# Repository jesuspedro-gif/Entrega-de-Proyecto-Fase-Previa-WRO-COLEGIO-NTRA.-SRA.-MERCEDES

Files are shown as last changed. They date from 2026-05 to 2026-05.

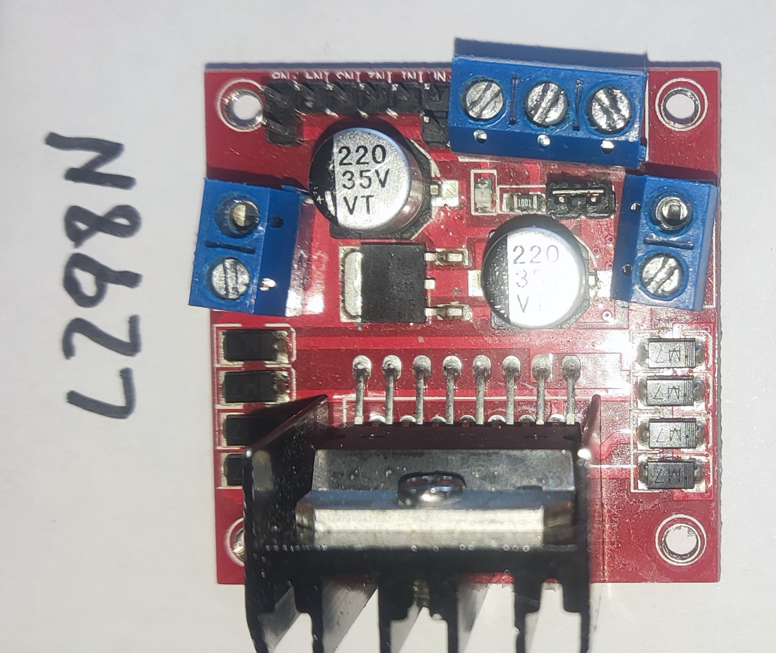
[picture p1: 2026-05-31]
images/L298N .jpeg

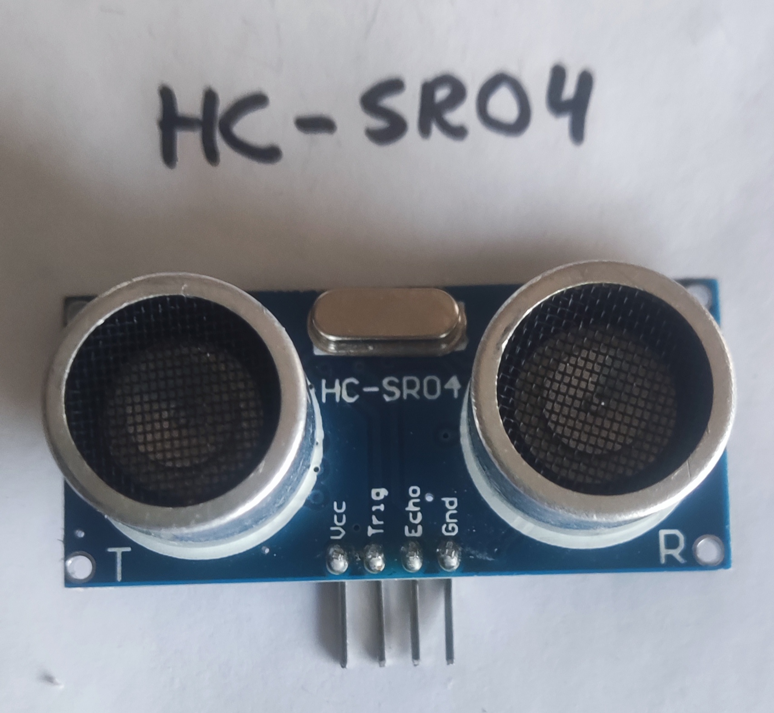
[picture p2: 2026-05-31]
images/HC-SR04.jpeg

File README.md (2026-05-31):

# TECHNICAL MEMORANDUM: WRO FUTURE ENGINEERS

## 1. OUR PROJECT

* **Project Title:** THE BEST FAILURES
* **Category:** WRO Future Engineers
* **Team Name:** Colegio Nuestra Señora de las Mercedes
* **Members:** Sergio, Isaac, and Martín
* **School:** Colegio Nuestra Señora de las Mercedes (Herencia, Ciudad Real)
* **Year:** 2026

---

## 2. INTRODUCTION AND STRATEGY

We built our robot using the components provided to our school through the **ESCUELA 4.0** program. Combining this material with a 3D printer and a laser cutter, we designed and manufactured all the necessary structural parts.

### 2.1 Component and Software Summary
Our robot is built around a **BBC micro:bit V2** coupled with a **KeyStudio expansion shield**. Connected to this setup are:
* A **Huskylens AI camera** for vision tracking.
* An **SG90 180° servo motor** to control a Lego-built rack-and-pinion steering mechanism.
* A geared **DC motor** driving the rear axle for propulsion.
* Three **HC-SR04 ultrasonic distance sensors** to avoid wall collisions.
* An **L298N motor driver module**.
* A battery holder for two **18650 Li-ion batteries** and a power switch.

The robot is capable of navigating an enclosed circuit between walls, avoiding obstacles, and steering to the right when it detects red prisms, or to the left when it detects green prisms.

### 2.2 Objectives
1. Design a lightweight robot using the available school components.
2. Achieve consistent and reliable baseline movement.
3. Complete full laps around the track autonomously.
4. Correctly identify and avoid colored game pieces by steering to the appropriate side.

---

## 3. MECHANICAL DESIGN (HARDWARE)

### 3.1 Chassis Structure
The chassis is made from **3mm MDF (Medium-Density Fibreboard)**, designed in *Inkscape* and manufactured using a laser cutter. It features a dual-layer layout:
* **Lower Deck:** Houses the drive motor, steering assembly, batteries, and servo motor to maintain a low center of gravity.
* **Upper Deck:** Hosts the micro:bit, expansion shield, motor controller, and sensors.

Additional custom components were 3D-printed, including custom gears, camera mounts, axles, and ultrasonic sensor mounts, assembled using standard screws and expansion kit pieces.

* **Total Weight:** 1.2 kg
* **Dimensions:** 120 x 180 x 150 mm

### 3.2 Steering System
The vehicle implements an **Ackermann-inspired steering geometry**, executed mechanically using a Lego rack-and-pinion mechanism. This assembly is driven by an SG90 servo motor linked via custom 3D-printed gears.

### 3.3 Drivetrain & Traction
* **Motor:** Geared DC motor with a 1:48 reduction ratio.
* **Gear Ratio:** 1:1 (using two identical interlocking gears).
* **Drive Type:** Rear-wheel drive (RWD).

### 3.4 Component Distribution
By placing the heavy batteries and the drive motor on the lowest deck, we effectively minimized the center of mass to maximize stability. The upper section houses the control electronics and vision systems to keep them protected and clear of mechanical linkages.

---

## 4. ELECTRONICS AND SENSORS

### 4.1 Main Controller
* **BBC micro:bit V2:** Selected due to its accessibility, block-based programming environment, and direct availability at our school. It handles all control logic via its I2C and digital interfaces.

### 4.2 Vision Sensors
* **Huskylens V1 AI Camera:** Embedded vision processor fully compatible with the micro:bit via I2C, featuring native algorithms for color and object recognition.

### 4.3 Distance and Orientation Sensors
* **Distance Sensors:** 3x **HC-SR04 ultrasonic sensors** configured to measure distances to front, left, and right walls to prevent collisions.
* **Gyroscope:** While the micro:bit features a built-in internal gyroscope and compass, we encountered programming limitations and did not successfully integrate them into the final steering loop.

### 4.4 Batteries & Power Management
* **Cells:** 2x **Panasonic NCR18650B Li-ion cells** (3400 mAh, 3.7V each, wired in series).
* **Regulation:** Voltage regulation is managed directly through the KeyStudio sensor expansion shield to distribute clean power across all modules.

---

## 5. SOFTWARE (PROGRAMMING)

### 5.1 Development Environment
The software was developed using the cloud-based **Microsoft MakeCode** platform utilizing standard extension blocks rather than low-level text libraries, maintaining a Scratch-like block architecture.

### 5.2 AI Camera Setup
Using the Huskylens extension, the initialization routine starts the camera over an I2C connection and switches the internal algorithm to color recognition mode.

### 5.3 Flowchart Logic
The robot continuously reads distance data while looking out for any visual color triggers. It branches its navigation rules based on whether a colored target block is active within the camera's view matrix.

### 5.4 Source Code (MakeCode JavaScript)

```javascript
// Function to move backward
function Atras (tiempo: number) {
    pins.digitalWritePin(DigitalPin.P8, 0)
    pins.digitalWritePin(DigitalPin.P2, 1)
    pins.analogWritePin(AnalogPin.P1, 600)
    basic.pause(tiempo)
    pins.digitalWritePin(DigitalPin.P1, 0)
}

// Function to move forward
function Adelante (tiempo: number) {
    pins.digitalWritePin(DigitalPin.P2, 0)
    pins.digitalWritePin(DigitalPin.P8, 1)
    pins.analogWritePin(AnalogPin.P1, 600)
    basic.pause(tiempo)
    pins.digitalWritePin(DigitalPin.P1, 0)
}

// Button A event trigger: Starts loops for round 1&2 (no objects) or 3&4 (with objects)
input.onButtonPressed(Button.A, function () {
    c = huskylens.readBox_s(Content3.ID)
    if (c <= 0) {
        while (true) {
            sinobjetos()
        }
    } else {
        while (true) {
            objetos()
        }
    }
})

// Navigation loop for rounds 3 and 4 (Obstacle interaction)
function objetos () {
    // Define and fetch data from variables
    c = huskylens.readBox_s(Content3.ID)
    posx = huskylens.readeBox_index(1, 1, Content1.xCenter)
    huskylens.writeName(1, "Rojo")
    
    df = sonar.ping(
    DigitalPin.P16,
    DigitalPin.P15,
    PingUnit.Centimeters
    )
    dd = sonar.ping(
    DigitalPin.P13,
    DigitalPin.P14,
    PingUnit.Centimeters
    )
    di = sonar.ping(
    DigitalPin.P12,
    DigitalPin.P11,
    PingUnit.Centimeters
    )
    
    if (c <= 0) {
        // When approaching a front wall
        if (df < 26) {
            // Evaluate best opening to turn
            if (dd > di) {
                basic.showIcon(IconNames.House)
                parar(100)
                servos.P0.setAngle(55)
                Atras(600)
                parar(100)
                servos.P0.setAngle(125)
                Adelante(300)
            } else {
                basic.showIcon(IconNames.Cow)
                parar(100)
                servos.P0.setAngle(125)
                Atras(600)
                parar(100)
                servos.P0.setAngle(55)
                Adelante(300)
            }
        } else {
            // Keep centered between side walls
            if (dd > di || 10 > di) {
                parar(50)
                servos.P0.setAngle(125)
                Adelante(200)
            } else if (dd < di || 10 > dd) {
                parar(50)
                servos.P0.setAngle(55)
                Adelante(200)
            }
        }
    } else if (c == 1) {
        color_rojo()
    } else if (c == 2) {
        color_verde()
    }
}

// Green object handling routine
function color_verde () {
    if (posx >= 160) {
        servos.P0.setAngle(110)
        Atras(500)
        servos.P0.setAngle(55)
        Adelante(400)
    } else {
        servos.P0.setAngle(110)
        Atras(500)
        servos.P0.setAngle(55)
        Adelante(400)
    }
}

// Base navigation loop when no objects are detected (Rounds 1 & 2)
function sinobjetos () {
    df = sonar.ping(
    DigitalPin.P16,
    DigitalPin.P15,
    PingUnit.Centimeters
    )
    dd = sonar.ping(
    DigitalPin.P13,
    DigitalPin.P14,
    PingUnit.Centimeters
    )
    di = sonar.ping(
    DigitalPin.P12,
    DigitalPin.P11,
    PingUnit.Centimeters
    )
    
    if (df < 25) {
        if (dd > di) {
            basic.showIcon(IconNames.House)
            parar(100)
            servos.P0.setAngle(55)
            Atras(600)
            parar(100)
            servos.P0.setAngle(110)
            Adelante(300)
        } else {
            basic.showIcon(IconNames.Cow)
            parar(100)
            servos.P0.setAngle(110)
            Atras(600)
            parar(100)
            servos.P0.setAngle(55)
            Adelante(300)
        }
    } else {
        if (dd > di || 10 > di) {
            servos.P0.setAngle(110)
        } else if (dd < di || 10 > dd) {
            servos.P0.setAngle(55)
        }
        Adelante(100)
    }
}

// Red object handling routine
function color_rojo () {
    if (posx <= 160) {
        servos.P0.setAngle(55)
        Atras(500)
        servos.P0.setAngle(110)
        Adelante(400)
    } else {
        servos.P0.setAngle(55)
        Atras(500)
        servos.P0.setAngle(110)
        Adelante(400)
    }
}

// Braking and delay function
function parar (t: number) {
    pins.analogWritePin(AnalogPin.P1, 0)
    basic.pause(t)
}

// Global variable initializations
let di = 0
let dd = 0
let df = 0
let posx = 0
let c = 0
servos.P0.setAngle(90)
c = 0
huskylens.initI2c()
huskylens.initMode(protocolAlgorithm.ALGORITHM_COLOR_RECOGNITION)
pins.digitalWritePin(DigitalPin.P2, 0)
pins.digitalWritePin(DigitalPin.P8, 1)

loops.everyInterval(500, function () {
    huskylens.request()
})

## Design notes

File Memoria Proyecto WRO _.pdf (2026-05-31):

# MEMORIA TÉCNICA: WRO FUTURE ENGINEERS

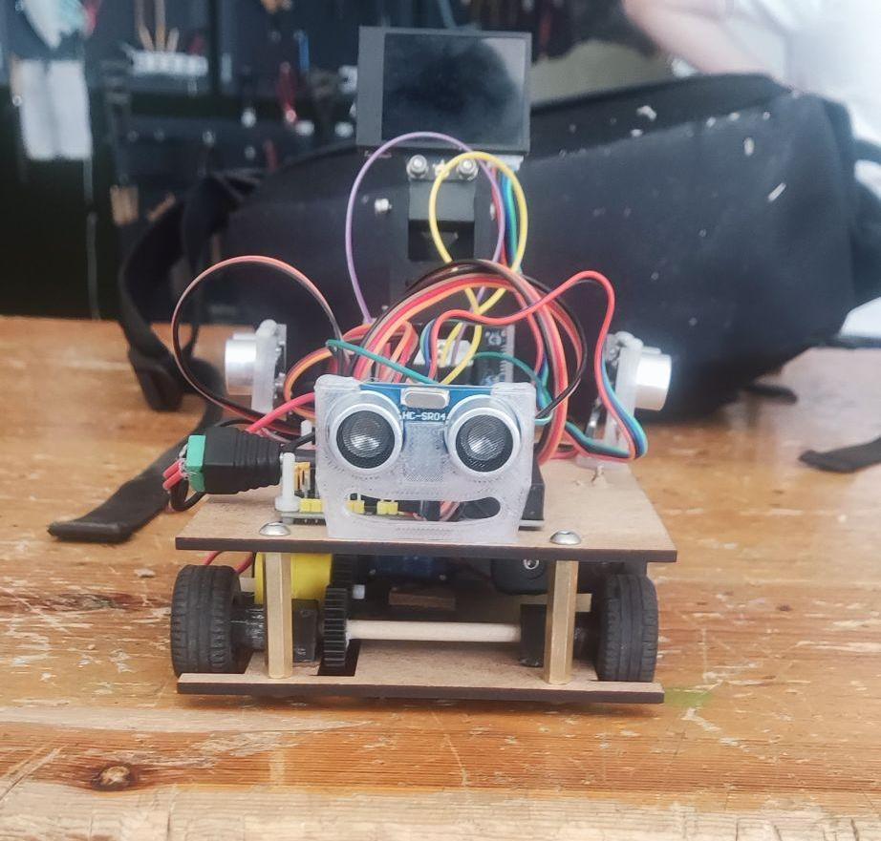
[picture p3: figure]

## Contenido

1. NUESTRO PROYECTO

Título del proyecto: THE BEST FAILURES Categoría: WRO Future Engineers Nombre del equipo: Colegio Nuestra Señora de las Mercedes Integrantes: Sergio, Isaac y Martín Centro: Colegio Nuestra Señora de las Mercedes-Herencia- Ciudad Real Año: 2026

2. INTRODUCCIÓN Y ESTRATEGIA

Hemos construido nuestro robot utilizando los componentes que le dieron a nuestro colegio por el programa ESCUELA 4.0. Utilizando este material junto con la impresora 3D y la cortadora láser hemos construido todas las piezas.

2.1 Resumen de componentes y programa

Hemos utilizado una microbit con una expansión (Shield) de KeyStudio, a la que hemos conectado una cámara con IA Huskylens, un servo SG90 de 180º para controlar la dirección de cremallera hecha con Lego, un motor DC con reductora puesto para mover el eje trasero, 3 sensores de ultrasonido Hc-sr04, un controlador de motor L298N, un portabaterías para dos baterías 18650 y un interruptor. El robot es capaz de desplazarse de forma que recorra un circuito entre paredes y también evitar obstáculos y pasar por la derecha si ve prismas rojo y por la izquierda si los ve verde.

2.2 Objetivos

- Diseñar un robot ligero utilizando los componentes que tenemos.
- Empezar por que el robot se mueva.
- Intentar dar vueltas al circuito.
- Si es posible esquivar las piezas de colores por su lado.

3. DISEÑO MECÁNICO (HARDWARE)

3.1 Estructura del chasis

El chasis es DM de 3mm, y lo hemos diseñado con inkscape y luego cortado en la cortadora láser. Tiene una parte inferior donde va el motor, la dirección, las baterías, el servo, la dirección y una parte superior en la que están el resto de componentes. También lleva piezas diseñadas en 3D como los engranajes, soporte para la cámara, ejes y sensores de ultrasonido, también lleva tornillos y piezas de la caja de expansión de la microbit.

Peso total: 1,2kg
Dimensiones: [120 x 180 x 150 mm]

3.2 Sistema de dirección

La dirección es de tipo Ackerman, aunque realmente es cremallera de Lego, lleva un servomotor SG-90 9G de 180º.

3.3 Sistema de tracción

Motor: Motor DC con reductora incorporada 1:48 Relación de marchas: 1:1 (los dos engranajes son iguales) Tipo de tracción: Trasera

3.4 Distribución de componentes

Las baterías y el motor en la parte inferior pretenden mantener equilibrado el chasis, hemos colocado los componentes para que no tenga más peso en ningún lado y no influya en su movimiento.

4. ELECTRÓNICA Y SENSORES

4.1 Controlador principal

Microbit V.2. Es fácil de programar por bloques y teníamos en nuestro colegio. Se pueden conectar a través de la tarjeta de expansión la cámara y varios sensores.

4.2 Sensores de visión

Cámara utilizada: Huskylens V.1. Compatible con microbit y dispone de una extensión que facilita su uso. La utilizamos para detectar colores, el color rojo y el verde.

4.3 Sensores de distancia y orientación

Sensores de distancia: el robot lleva 3 sensores de ultrasonidos HC-SR04, para detectar las paredes y que no se choque. No hemos podido poner uno en la parte trasera porque no teníamos más pines para conectar.
Giroscopio: La microbit lleva giroscopio y brújula incorporada, pero no hemos conseguido programarlas bien.

4.4 Baterías

Baterías usadas: 2xNCR18650B Li-ion MH12210 Panasonic 3400 mAh 3.7v y los reguladores de voltaje los lleva la Sensor Shield Keystudio v2.0 for Microbit

5. SOFTWARE (PROGRAMACIÓN)

5.1 Programación en la nube en makecode, utilizado en vez de librerías extensiones, las extensiones utilizadas han sido las siguientes: Huskylens V.1, Servo y Sónar. Programación por bloques tipo Scratch.

5.2 Uso de la Cámara IA Huskylens

Al usar la extensión de Huskylens, lo primero que debemos hacer es iniciar la camara por conectada por I2C y seleccionar el modo de trabajo a reconocimiento de color. Detectamos 3 colores Id1 color rojo, Id2 color verde e Id3 color de aparcamiento. No detectamos líneas en el suelo.

5.3 Diagrama de flujo

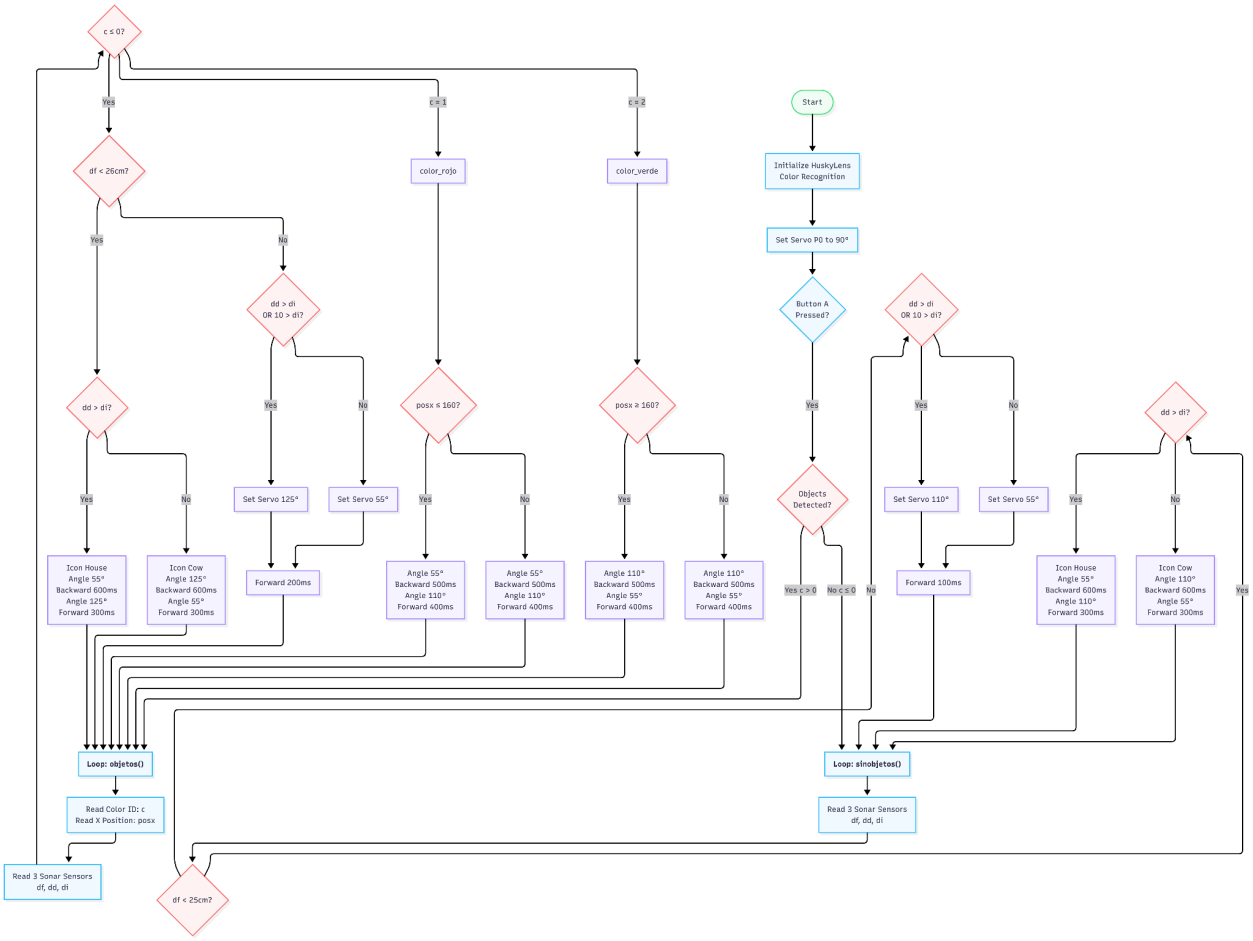
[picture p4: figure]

5.4 Código

## // para retroceder function Atras (tiempo: number) { pins.digitalWritePin(DigitalPin.P8, 0) pins.digitalWritePin(DigitalPin.P2, 1) pins.analogWritePin(AnalogPin.P1, 600) basic.pause(tiempo) pins.digitalWritePin(DigitalPin.P1, 0)

}

## // avanzar function Adelante (tiempo: number) { pins.digitalWritePin(DigitalPin.P2, 0) pins.digitalWritePin(DigitalPin.P8, 1)

## pins.analogWritePin(AnalogPin.P1, 600) basic.pause(tiempo) pins.digitalWritePin(DigitalPin.P1, 0)

}

## // inicio al boton A, repite la funcion de las rondas 1 y 2 o la 3 y 4(con objetos) input.onButtonPressed(Button.A, function () { c = huskylens.readBox_s(Content3.ID) if (c <= 0) { while (true) { sinobjetos()

}

## } else { while (true) { objetos()

}
}
})

## // programa para las rondas 3 y 4 function objetos () { // definimos variables c = huskylens.readBox_s(Content3.ID)

posx = huskylens.readeBox_index(1, 1,

## Content1.xCenter) huskylens.writeName(1, "Rojo") df = sonar.ping(

DigitalPin.P16,
DigitalPin.P15,

## PingUnit.Centimeters

)

## dd = sonar.ping(

DigitalPin.P13,
DigitalPin.P14,

## PingUnit.Centimeters

)

## di = sonar.ping(

DigitalPin.P12,
DigitalPin.P11,

## PingUnit.Centimeters

)

if (c <= 0) { // cuando se acerque a la pared if (df < 26) { // comprueba la dirección donde deba girar if (dd > di) { basic.showIcon(IconNames.House) parar(100) servos.P0.setAngle(55) Atras(600) parar(100) servos.P0.setAngle(125) Adelante(300) } else { basic.showIcon(IconNames.Cow) parar(100) servos.P0.setAngle(125) Atras(600) parar(100) servos.P0.setAngle(55) Adelante(300)

}

## } else { // se mantiene en un punto intermedio de las paredes if (dd > di || 10 > di) {

## parar(50) servos.P0.setAngle(125) Adelante(200) } else if (dd < di || 10 > dd) {

## parar(50) servos.P0.setAngle(55) Adelante(200)

}
}

## } else if (c == 1) { color_rojo() } else if (c == 2) { color_verde()

}
}

## function color_verde () { if (posx >= 160) { servos.P0.setAngle(110) Atras(500) servos.P0.setAngle(55) Adelante(400) } else { servos.P0.setAngle(110) Atras(500) servos.P0.setAngle(55)

## Adelante(400)

}
}

## function sinobjetos () { df = sonar.ping(

DigitalPin.P16,
DigitalPin.P15,

## PingUnit.Centimeters

)

## dd = sonar.ping(

DigitalPin.P13,
DigitalPin.P14,

## PingUnit.Centimeters

)

## di = sonar.ping(

DigitalPin.P12,
DigitalPin.P11,

## PingUnit.Centimeters

)

## // quitar la diferencia e igualación a 0 cuando haya un centro en el tablero if (df < 25) { if (dd > di) { basic.showIcon(IconNames.House) parar(100) servos.P0.setAngle(55) Atras(600) parar(100) servos.P0.setAngle(110) Adelante(300)

## } else { basic.showIcon(IconNames.Cow) parar(100) servos.P0.setAngle(110) Atras(600) parar(100) servos.P0.setAngle(55) Adelante(300)

}

## } else { if (dd > di || 10 > di) {

## servos.P0.setAngle(110) } else if (dd < di || 10 > dd) {

## servos.P0.setAngle(55)

}

## Adelante(100)

}
}

## // cuando vea el rojo function color_rojo () { if (posx <= 160) { servos.P0.setAngle(55) Atras(500) servos.P0.setAngle(110) Adelante(400) } else { servos.P0.setAngle(55) Atras(500) servos.P0.setAngle(110) Adelante(400)

}
}

## function parar (t: number) { pins.analogWritePin(AnalogPin.P1, 0) basic.pause(t)

}

## let di = 0 let dd = 0 let df = 0 let posx = 0 let c = 0 servos.P0.setAngle(90)

c = 0

## huskylens.initI2c() huskylens.initMode(protocolAlgorithm.ALGORITHM_COLOR_REC OGNITION) pins.digitalWritePin(DigitalPin.P2, 0) pins.digitalWritePin(DigitalPin.P8, 1) loops.everyInterval(500, function () { huskylens.request()

})

5.5 Explicación

La forma en la que el robot toma decisiones es bastante simple: primero mira qué está detectando con sus sensores y con la cámara HuskyLens, y según eso decide qué hacer. Es como si tuviera “modos”. Si no ve colores especiales, entra en el modo normal y usa los sensores ultrasónicos para saber si tiene un obstáculo delante o si está demasiado cerca de una pared. Cuando detecta algo muy cerca, retrocede y gira hacia el lado donde haya más espacio. Si no hay obstáculos, intenta mantenerse centrado entre las paredes moviendo el servo un poco hacia la izquierda o la derecha.

Además, el robot también reacciona a los colores que detecta la cámara. Si ve rojo o verde, cambia a otro modo y hace una maniobra especial: gira el servo, retrocede y luego avanza hacia el lado que corresponde. Es como si el color le diera una orden rápida para cambiar de dirección.

Tiene 6 funciones:

1. Atras

Esta función hace que el robot vaya hacia atrás durante el tiempo que tú le digas. Básicamente enciende los pines del motor en la dirección contraria y le mete potencia. Luego espera el tiempo indicado y para el motor. Es como decirle: “retrocede un poco y luego quieto”.

2. Adelante

Esta es lo mismo, pero al revés: el robot avanza. Activa los pines para que el motor gire hacia adelante y le da fuerza. Después de avanzar el tiempo que le pongas, hace unas maniobras extra (girar servo, retroceder, etc.) según lo que esté pasando. Es como su movimiento principal.

3. color_verde

Cuando la cámara detecta el color verde, el robot hace una maniobra especial: gira el servo, retrocede y luego avanza hacia un lado. Da igual si el verde está a la izquierda o derecha, porque en tu código hace lo mismo siempre. Es como si dijera: “¡He visto verde, toca esquivar!”.

4. sinobjetos

Esta función es la que usa cuando no hay colores detectados. Aquí el robot mira las distancias con los sensores ultra sonidos. Si tiene algo delante, decide hacia qué lado girar según dónde haya más espacio. Si no hay nada, solo corrige su dirección para mantenerse centrado. Es como su modo “normal”.

5. color_rojo

Funciona igual que la del color verde, pero para el rojo. Cuando lo ve, retrocede, gira el servo y avanza hacia el lado contrario. Es como una reacción rápida para evitar algo marcado en rojo.

6. parar

Esta es la función más simple: corta la potencia del motor y espera un momento. Sirve para que el robot haga pausas entre movimientos y no se vuelva loco.

6. PRUEBAS, ITERACIONES Y RESULTADOS

6.1 Proceso de pruebas

No disponemos de pista de pruebas y hemos simulado en la casa de Isaac, en la cocina, solo disponíamos de un cuadrado de 1x1 m y las paredes de la cocina. Parece que puede dar algunas vueltas y evitar algún obstáculo.

6.2 Problemas encontrados y soluciones aplicadas

Problema 1: Pequeño incendio en portabaterías al ponerlas mal.
Solución: Reemplazo de portabaterías
Problema 2: No funcionaban los sensores de ultrasonidos.
Solución: Problema de pines, algunos pines están reservados y los usábamos para los sensores, tuvimos que mirar los pines que podíamos utilizar.
Problema 3: Se quemó el servo.
Solución: Cambio de servo.
Problema 4: El robot gira mal hacia la izquierda.
Solución: Seguimos pensando en ello.

6.3 Tiempos y rendimiento

En la competición veremos lo que hace nuestro robot.

7. CONCLUSIONES Y TRABAJO FUTURO

7.1 Lecciones aprendidas

Hemos aprendido a ser constantes y trabajar, aunque las cosas muchas veces no salen bien. Si pensamos los 3 las cosas salen mejor que si las piensa 1. También hemos aprendido que hay que pensar y contar hasta 10 antes de encender el robot.

7.2 Mejoras futuras

- Cambiar la dirección, porque no va recto cuando queremos.
- Motor y eje trasero integrados.
- Chasis más resistente.
- Si queremos usar 4 sensores de ultrasonidos utilizar otra placa.
8. Componentes y piezas.

8.1 Lista de materiales y justificación.

Componentes | Cantidad | Precio | Imagen
Tabla 40x40cm dm 3mm | 1 | 2 €
Motor DC con reductora | 1 | Disponible en el cole.
Servo SG90 9G 180º | 1 | Disponible en el cole.
L298N | 1 | Disponible en el cole.
Piezas Lego dirección | - | Disponible en el cole.
Portabaterías 18650 | 2 | 3,09 €

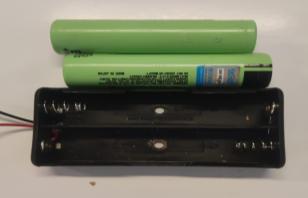
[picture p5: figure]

Baterías Li-ion Panasonic MH12210 | 2 | Disponible en el cole.
Shield Keystudio V.2 | 1 | 9,91 €

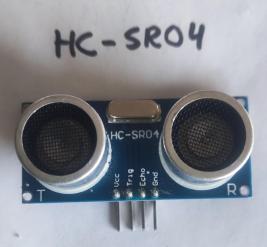
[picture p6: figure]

Hc-sr04 | 3 | Disponible en el cole.

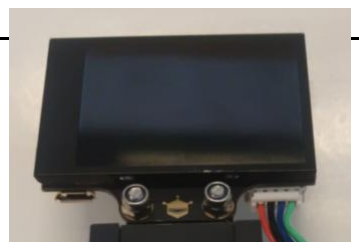
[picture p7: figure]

Cámara Huskylens V.1 | 1 | Disponible en el cole.

Ruedas Lego 30.4x14 | 4 | Disponible en el centro.

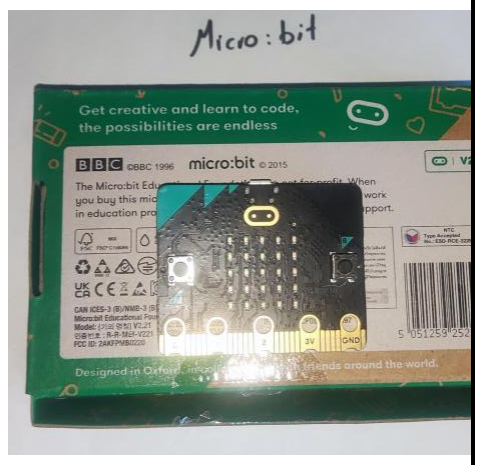
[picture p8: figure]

Placa Micro:bit V2 | 1 | Disponible en el centro

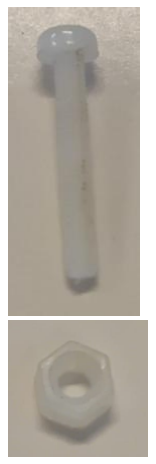
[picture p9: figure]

Tornillería varios

Conector DC | 1 | 0,70 €
Interrupto | 1 | Disponible en el centro

8.2 Justificación de la elección de los componentes:

Componentes:
- Motor de corriente continua con reductora.
Hemos utilizado un motor con reductora ya que es un motor versátil ya que puede ir hacia adelante y hacia atrás modificando su velocidad además de hemos podido enganchar los engranajes para que pueda avanzar y retroceder

- L298N, para poder utilizar el motor.
Hemos utilizado el L298N ya que el consumo del motor es tan grande que la placa micro bit no lo soporta por lo que lo necesita para controlar cuál será la velocidad y sentido del movimiento
- Placa microbit + Shield Keyestudio

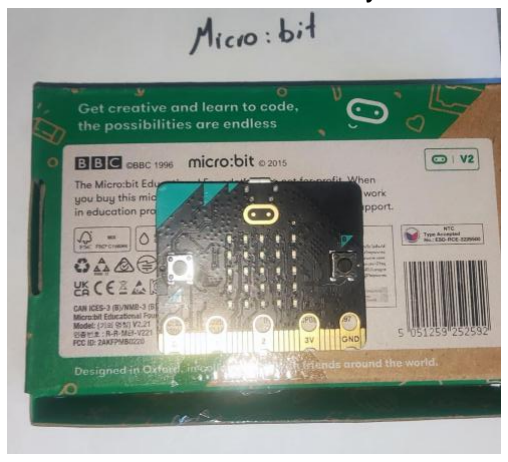
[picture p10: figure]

Hemos elegido la placa micro bit por su gran compatibilidad con la huskylens y porque es fácil de programar

- Portabaterías 18650 LIPO 2 en serie.
Hemos utilizado un portapilas que proporciona la energía suficiente para que todo funcione bien y para que el motor de corriente continua obtenga la suficiente energía para que pueda funcionar
- Husky Lens V1, cámara IA

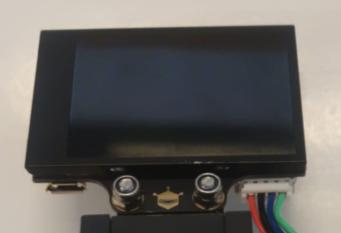
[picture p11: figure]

Utilizamos la husky lens para poder reconocer los colores y así poder realizar la segunda prueba con mayor facilidad

- HC-SR04
Lo hemos utilizado para poder medir distancias y poder hacer que se mueva con mayor precisión a la hora de la primera prueba y poeder mantener distancias con los bordes negros ademas de que mejoran la percepcion de los obstaculos del robot
- Servo 180º.
Hemos utilizado el servo 180 para poder tener mayor manejo a la hora de poder girar con la cremallera con piezas lego y así permitir que vaya a izquierda y derecha
- Ruedas Lego

Hemos utilizado ruedas de lego ya que podíamos imprimir en 3D piezas que encajen con el sistema de movimiento y porque al no tener un gran tamaño podemos estructurar el espacio de forma más eficiente sin olvidar que al estar hechas de goma su fricción es mayor lo que hace que los movimientos del robot sean más precisos.

8.3 Planos y diseños CAD y referencias:

Chasis 1: chasis robot1.svg

Chasis 2: chasis robot2.svg

Soporte Sensores de ultrasonido: diseño 3D "Escornabot Brivoi Compactus", creado por el usuario escornabot en 2016, está disponible en Thingiverse bajo licencia CC BY-SA 4.0. escornabot, "Escornabot Brivoi Compactus," Thingiverse, 2016. Disponible en: thingiverse.com.

Soporte Huslylens: El diseño 3D "huskylens Ai camera mount for FTC", creado por el usuario e_2249455 (Team Fusion 18142) en 2024, está disponible en Printables.com. Creative Commons Atribución-NoComercial 4.0 Internacional (CC BY-NC 4.0). e_2249455. (2024). Huskylens Ai camera mount for FTC [Modelo 3D]. Printables. (https://www.printables.com/model/942759-huskylens-ai-camera-mount-for-ftc?lang=es) https://www.printables.com/model/942759-huskylens-ai-camera-mount-for-ftc Archivos: “husky lens mount part 1.stl”, “husky lens mount part 2.stl”

Acople servo eje lego: creado por nosotros en Tinkercad.
Archivo: “acople lego servo.stl”

Acople eje 5mm a rueda lego: creado por nosotros en Tinkercad.
Archivo: “Acople lego 5mm.stl”

Engranajes: Modificación del diseño 3D "Engranajes para usar con Servo Sg90", creado por el usuario jjnm5 en 2015, está disponible en Thingiverse bajo licencia CC BY 4.0.
jjnm5. (2015). Engranajes para usar con Servo Sg90 [Modelo 3D]. Thingiverse. https://www.thingiverse.com/thing:797477
9. ANEXOS, REFERENCIAS Y FOTOS
- Repositorio público en GitHub: enlace (https://github.com/jesuspedro-gif/Entrega-de-Proyecto-Fase-Previa-WRO-COLEGIO-NTRA.-SRA.-MERCEDES)
- Fotografías del robot (desde todos los ángulos) y una fotografía del equipo.
- Vídeo demostrativo mostrando el robot funcionando de manera autónoma en las diferentes regiones

Misión 1 (https://youtube.com/shorts/GUf5SY0Ej4I?feature=share)
Misión 3 (https://youtube.com/shorts/9KETdzkMNOU?feature=share)

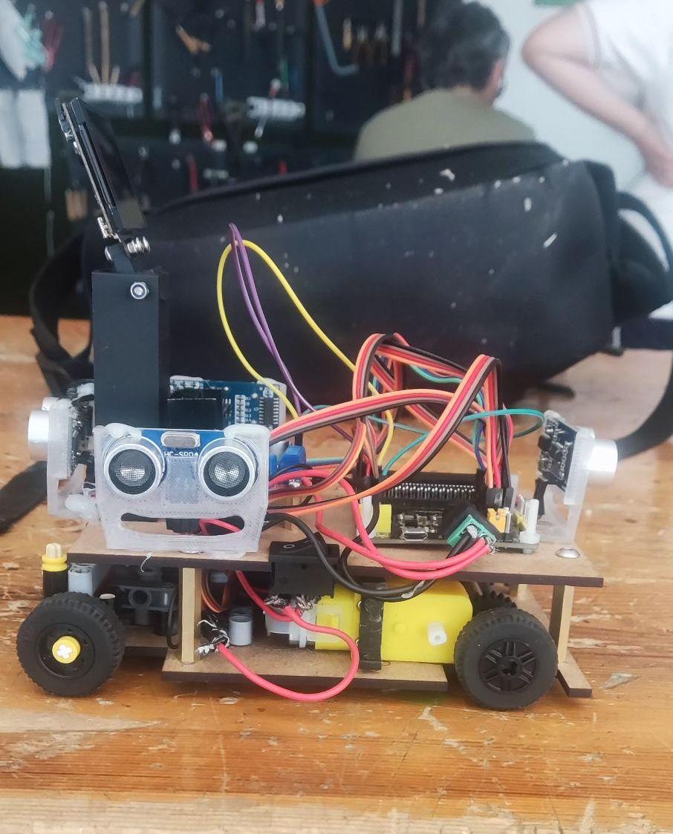
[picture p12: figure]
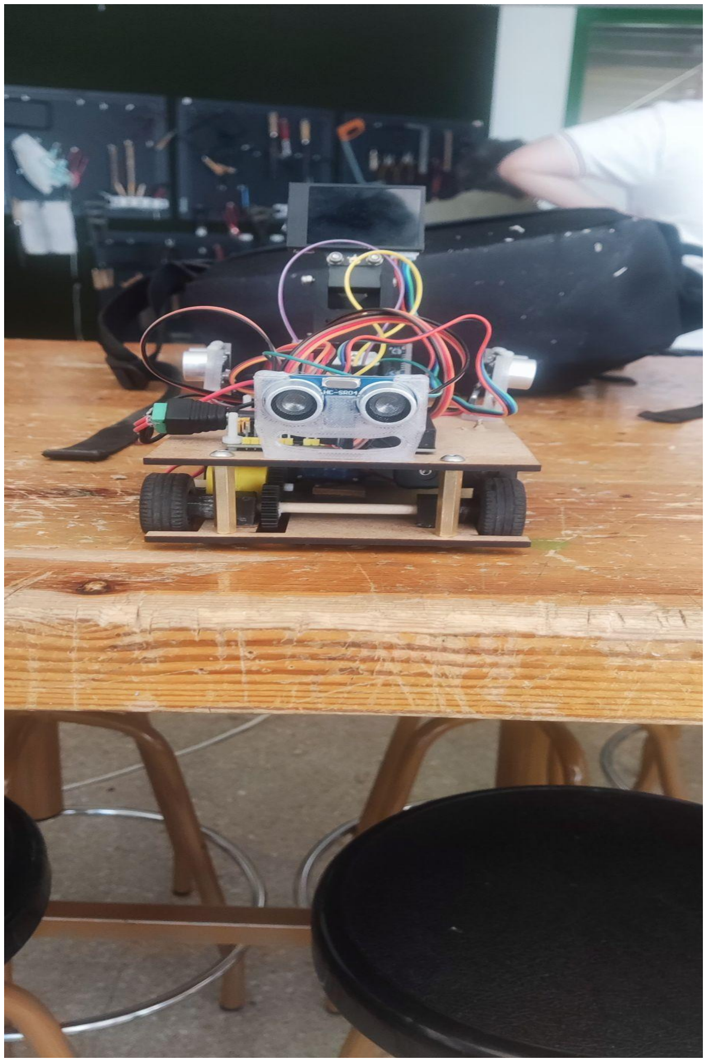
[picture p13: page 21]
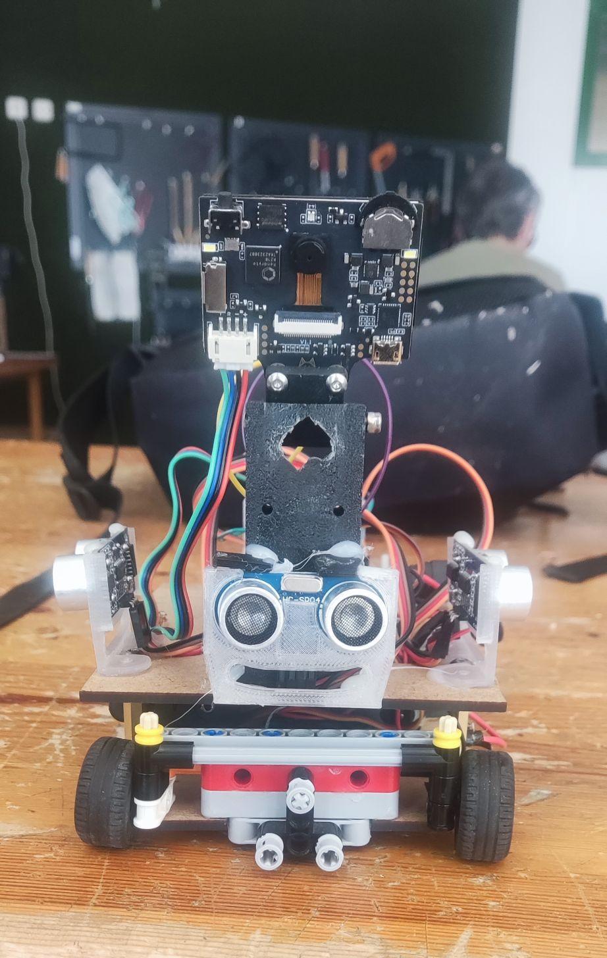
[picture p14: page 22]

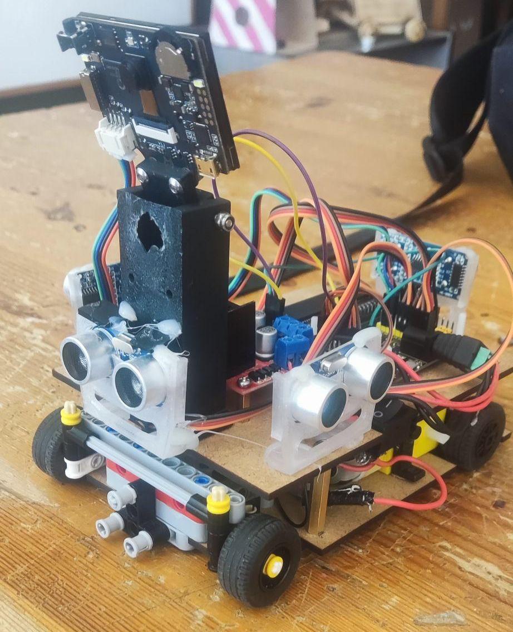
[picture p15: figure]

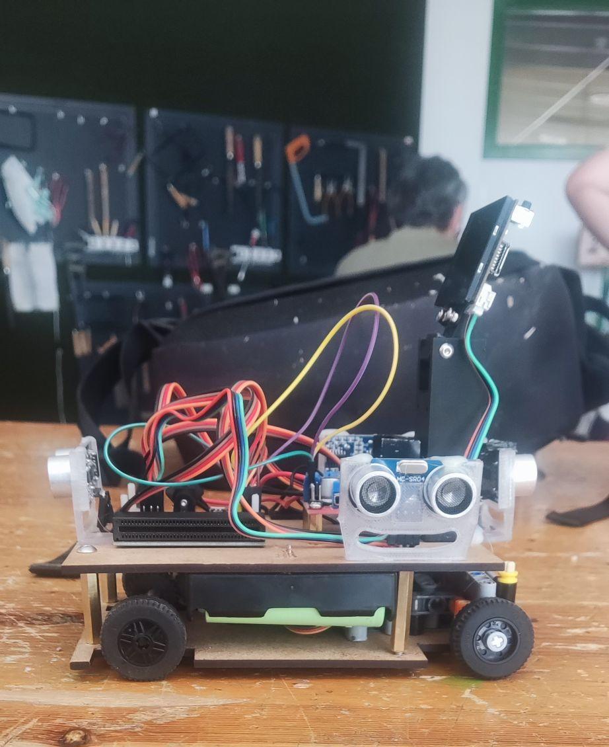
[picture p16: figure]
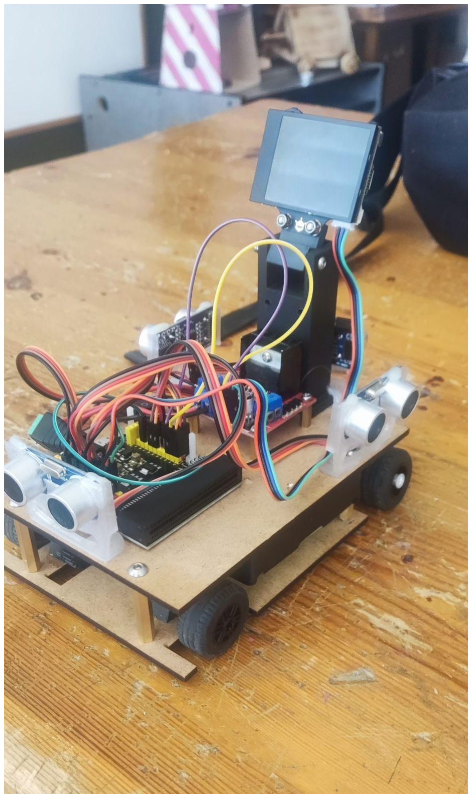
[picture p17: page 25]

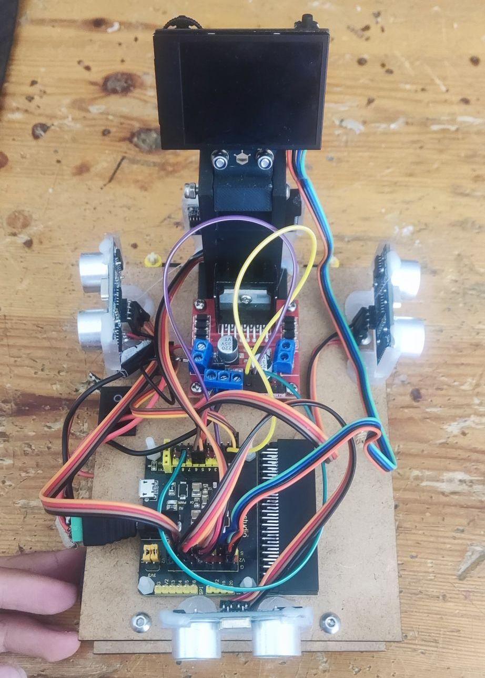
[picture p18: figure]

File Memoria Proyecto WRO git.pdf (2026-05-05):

WRO

JORNADAS DE ROBÓTICA, MAYO 2026 CIUDAD REAL COLEGIO NUESTRA SEÑORA DE LAS MERCEDES –HERENCIA-

Descripción técnica del robot:

Desarrollo: EL desarrollo del robot comenzó con una pequeña tabla de madera, creamos un prototipo y luego lo diseñados en u programa de dibujo vectorial para fabricar el chasis con la cortadora láser.
Está diseñado a dos niveles, en el nivel inferior está el sistema de dirección, motor servo y baterías, y en el nivel superior los componentes electrónicos.
Componentes:
- Motor de corriente continua con reductora.
- L298N, para poder utilizar el motor.
- Placa microbit + Shield Keyestudio
- Portabaterías 18650 LIPO 2 en serie.
- Huskylens V1, cámara IA
- Interruptor
- Servo 180º.
- Ruedas Lego
- Sistema de cremallera + bielas fabricado con piezas de lego.
- Piezas diseñadas en 3D: engranajes, soportes y acoples.

Problemas: después de arreglar un problema del chasis, comenzamos a diseñar la planta superior en la que se encuentra la placa microbit, su expansión, el interruptor de encendido y el L298N, además de un soporte para que sujete el motor 180º de la parte inferior y mientras, en la parte inferior instalamos un portapilas para alimentar los componentes electrónicos y también el motor de corriente continua con reductora. Finalmente instalamos los pilares que mantienen unidas las dos partes y conectamos todos los componentes electrónicos con cables. Sin embargo, el interruptor se rompió por lo que tuvimos que cambiarlo al interruptor actual, por último imprimimos en una impresora 3D un soporte para mantener la cámara de IA huskylens más elevada que el resto de componentes y la conectamos a la expansión de la placa microbit. Tras terminar el robot, comenzamos a programar el robot para completar una serie de circuitos de obstáculos creados por nosotros mismos para encontrar y corregir errores de programación.

Decisiones técnicas:
- Uso de cámara IA, elevándola unos centímetros para controlar el horizonte.
- Usar microbit y tarjetas de expansión.
- Robot de tamaño pequeño.

Resultados obtenidos:
- Hemos conseguido un robot básico que no se mueve como nos hubiese gustado, pero que con más tiempo y dedicación podría haber funcionado muy bien. Movilidad:
- Servomotor 180º para dirección, con ángulos +- 45º
- Motor de corriente continua con reductora para tracción trasera.

- Ruedas y chasis con piezas de lego.
- L298N para alimentar el motor DC.

Alimentación:
- 2 Pilas LiPo 18650

Sensores:
- Cámara IA huskylens

Código empleado

/**

## * para no tener que apagar y encender para empezar de n uevo al pulsar a después de acabar

*/
// Función para avanzar de forma continua sin pausas.

## // Configura los pines de tracción hacia adelante y apli

ca la velocidad indicada.

function marchaContinua (velocidad: number) { // P2 a 0 y P8 a 1 determinan el sentido de giro del motor (Hacia adelante) pins.digitalWritePin(DigitalPin.P2, 0) pins.digitalWritePin(DigitalPin.P8, 1) // P1 regula la velocidad mediante una señal analógi ca (0 a 1023) pins.analogWritePin(AnalogPin.P1, velocidad)

}

## // BUCLE

// Se ejecuta infinitamente tras pulsar el botón A.

## input.onButtonPressed(Button.A, function () { while (true) { // 1. Condición de salida: Si la carrera terminó

, detenemos todo.

## if (carreraTerminada) { parar(0) return

}

## // 2. Lectura de la cámara HuskyLens huskylens.request() // Leemos el ID (Color) del objeto que está enfo cado Color = huskylens.readBox_s(Content3.ID) // Si detecta el color 4 (Meta), activa permanen temente el modo meta if (Color == 4) { modoMeta = true

}
// ==========================================

## // (Buscando la meta - Color 4)

// ==========================================

if (modoMeta) { // Muestra el icono de objetivo basic.showIcon(IconNames.Target) if (Color == 4) { // Leemos las coordenadas X e Y del cent ro del objeto posX = huskylens.readeBox(Color, Content 1.xCenter) posY = huskylens.readeBox(Color, Content 1.yCenter) // Lógica de dirección: Mantiene el obje to en el centro de la visión if (posX < 140) { // Gira para corregir a un lado servos.P0.setAngle(55) } else if (posX > 180) { // Gira para corregir al otro lado servos.P0.setAngle(135) } else { // Va recto si está centrado servos.P0.setAngle(90)

}

## // Acelera a máxima velocidad hacia la m eta marchaContinua(1023) // Si la coordenada Y es mayor a 200, el

objeto está muy bajo en la pantalla,

## // lo que significa que lo tenemos justo

delante.

## if (posY > 200) { carreraTerminada = true parar(0) // Muestra una X al terminar basic.showIcon(IconNames.No)

}

## } else { // Si perdemos de vista el color 4 : // Intentamos ir rectos medio segundo, p

or si lo encontramos.

## servos.P0.setAngle(90) marchaContinua(1023) basic.pause(500) // Si no reaparece, nos detenemos y term

inamos.

## carreraTerminada = true parar(0) basic.showIcon(IconNames.No)

}

## return

}
// ==========================================

## // LÓGICA DE EVADIR OBSTÁCULOS (Obstáculos IDs 1

, 2 y 3)
// ==========================================

## if (Color > 0 && Color <= 3) { // Leemos posición Y TAMAÑO del obstáculo de tectado

posX = huskylens.readeBox(Color, Content1.xC enter) posY = huskylens.readeBox(Color, Content1.yC enter) ancho = huskylens.readeBox(Color, Content1.w idth) alto = huskylens.readeBox(Color, Content1.he ight) // --- DETECCIÓN DE CHOQUE ---// Se echa para atrás si: // 1. Está muy abajo en la pantalla (posY >

140), señal de que está muy cerca.

## // 2. O es muy ancho (ancho > 100), es decir

, es un gran muro.
// 3. O es muy alto (alto > 100).

## if (posY > 140 || ancho > 100 || alto > 100)

{

## if (Color == 3) { // LÓGICA PARA PARED (Color 3) // Primero, da marcha atrás girando hacia el lado opuesto del muro if (posX >= 160) { servos.P0.setAngle(135) } else { servos.P0.setAngle(55)

}

## parar(150) // Marcha atrás durante 1 segundo atras(1023, 1000) parar(150) // Contravolante de salida: Cambia l a dirección y avanza para salir en forma de "S" if (posX >= 160) { servos.P0.setAngle(55) } else {

## servos.P0.setAngle(135)

}

## adelante(750, 600) // Termina la maniobra de "S" if (posX >= 160) { servos.P0.setAngle(135) } else { servos.P0.setAngle(55)

}

## adelante(750, 400) } else { // LÓGICA PARA OBSTÁCULOS PEQUEÑOS ( IDs 1 y 2 cerca) // Da un pequeño toque marcha atrás para alejarse if (Color == 1) { servos.P0.setAngle(55) } else { servos.P0.setAngle(135)

}

## parar(150) atras(1023, 400)

}

## // Después de maniobrar, pone las ruedas rectas servos.P0.setAngle(90) } else {

// --

## - AVANCE NORMAL / ESQUIVE DE LEJOS ---// Maniobra en "S" frontal, esquivando s in tener que frenar ni dar marcha atrás if (Color == 1) { servos.P0.setAngle(135) adelante(750, 400) servos.P0.setAngle(55)

adelante(750, 400) } else if (Color == 2) { servos.P0.setAngle(55) adelante(750, 400) servos.P0.setAngle(135) adelante(750, 400) } else if (Color == 3) { // Si el obstáculo 3 está lejos, esq uivamos hacia el lado más despejado if (posX >= 160) { servos.P0.setAngle(55) adelante(750, 400) servos.P0.setAngle(135) adelante(750, 400) } else { servos.P0.setAngle(135) adelante(750, 400) servos.P0.setAngle(55) adelante(750, 400)

}
}

## // Siempre ponemos la dirección al centr

o

## servos.P0.setAngle(90)

}

## } else {

// ========================================= =

## // NO VE NADA (Camino despejado)

// ========================================= =

## // Ruedas rectas y avanza a velocidad modera da para explorar servos.P0.setAngle(90) marchaContinua(750)

}
}
})
// Funciones de movimiento temporizado.

## // Configuran la dirección del motor y duración movimien

to.

## function adelante (velocidad: number, tiempo: number) { pins.digitalWritePin(DigitalPin.P2, 0) pins.digitalWritePin(DigitalPin.P8, 1) pins.analogWritePin(AnalogPin.P1, velocidad) basic.pause(tiempo)

}

## function parar (tiempo: number) { // Velocidad cero pins.analogWritePin(AnalogPin.P1, 0) basic.pause(tiempo)

}

## function atras (velocidad: number, tiempo: number) { // Invertimos los pines lógicos P2 y P8 para inverti r el giro del motor pins.digitalWritePin(DigitalPin.P2, 1) pins.digitalWritePin(DigitalPin.P8, 0) pins.analogWritePin(AnalogPin.P1, velocidad) basic.pause(tiempo)

}

## let alto = 0 let ancho = 0 let posY = 0 let posX = 0 let modoMeta = false let Color = 0 let carreraTerminada = false // Se pone la cremallera de la dirección en posición ini cial, apuntando recto servos.P0.setAngle(90)

// Inicializar la cámara por el bus I2C y configurar el algoritmo de colores huskylens.initI2c() huskylens.initMode(protocolAlgorithm.ALGORITHM_COLOR_REC OGNITION) // Preparar el controlador del motor para el avance (aun que no le da velocidad aún) pins.digitalWritePin(DigitalPin.P2, 0) pins.digitalWritePin(DigitalPin.P8, 1) // Indicador visual de que el robot está listo para empe zar basic.showIcon(IconNames.Happy) carreraTerminada = false

Funcionamiento

El objetivo es que un robot pueda esquivar obstáculos según las instrucciones dadas. Para ello hemos programado el robot teniendo en cuenta dos cosas:
- Esquivar obstáculos (representados por los colores 1, 2 y 3)
- Aparcar (4). Objetivo no conseguido.
Para lograr esto, el código combina el control de un motor DC para la tracción, un servomotor para la dirección y la cámara HuskyLens para reconocer los objetos(colores)

Inicio:
El robot usa una dirección de tipo "cremallera” controlada por un servomotor conectado al pin P0. El ángulo de 90 grados representa tener las ruedas rectas. Los ángulos 55 y 135 se usan para girar a los lados.

La Tracción (Motor DC en P1, P2 y P8): El avance y retroceso se controlan mediante tres pines. P2 y P8 actúan como interruptores lógicos (0 o 1) para decidir si el motor gira hacia adelante o hacia atrás. El pin P1 envía una señal analógica (PWM) que regula la velocidad del motor, desde 0 (parado) hasta 1023 (máxima velocidad).

La Cámara (HuskyLens): Se inicializa la comunicación I2C con la cámara y se configura en el modo de "Reconocimiento de Colores".

Funciones de Movimiento

Hemos creado funciones auxiliares:
Adelante (velocidad, tiempo) y atrás (velocidad, tiempo), avanza o retrocede durante unos milisegundos

Parar. El motor DC deja de funcionar.

Bucle
Al pulsar el botón A, el robot entra en un bucle infinito.
Primero: comprueba si ha terminado el recorrido; si es así, detiene los motores y sale del bucle, terminando el programa.
Si no ha terminado, la cámara HuskyLens analiza lo que está viendo y obtiene el ID(el color) del objeto detectado en el centro de la pantalla. Dependiendo de lo que vea, el robot tomará una de tres decisiones: ir a aparcar, esquivar un obstáculo o avanzar.
Si la cámara detecta el color con ID 4, el robot activa modoMeta = true, prioridad absoluta es alcanzar es aparcar.
Aceleración: El robot avanza a máxima velocidad (1023).
Obteniendo la coordenada X (izquierda/derecha) y la coordenada Y (arriba/abajo) del objeto en la pantalla de la cámara podemos tomar decisiones.
- Si el objeto está muy a la izquierda (X < 140), el servo gira hacia ese lado (ángulo 55).
- Si está muy a la derecha (X > 180), gira al otro lado (ángulo 135). Si está centrado entre 140 y 180, pone las ruedas rectas (ángulo 90).
- Si la coordenada Y del objeto es mayor que 200, significa que el objeto está en la parte inferior de la pantalla de la cámara. En visión artificial para robots de suelo, que un objeto "baje" en la pantalla significa que el robot se está acercando a él. Si supera 200, asume que ha tocado la meta, marca carreraTerminada = true, se detiene y muestra una "X" (IconNames.No) en la pantalla LED, indicando el fin del trayecto. Si pierde el objetivo de vista, intenta avanzar recto un momento y luego se rinde.
- Si encuentra una pared (Color 3): El robot frena, gira las ruedas en dirección contraria a donde está el centro de la pared, da marcha atrás, gira al lado opuesto y hace una maniobra en forma de "S" hacia adelante para sortearla.
- Si son obstáculos pequeños (Colores 1 y 2): El robot gira las ruedas, retrocede un poco para hacer espacio y luego endereza.
- El código asigna diferentes giros dependiendo de si es el color 1 (rojo), el color 2 (verde) o el color 3 (negro, pared).
- Cuando no ve nada, pone la dirección completamente recta (ángulo 90) y avanza a una velocidad moderada de 750 buscando constantemente algo en su entorno.

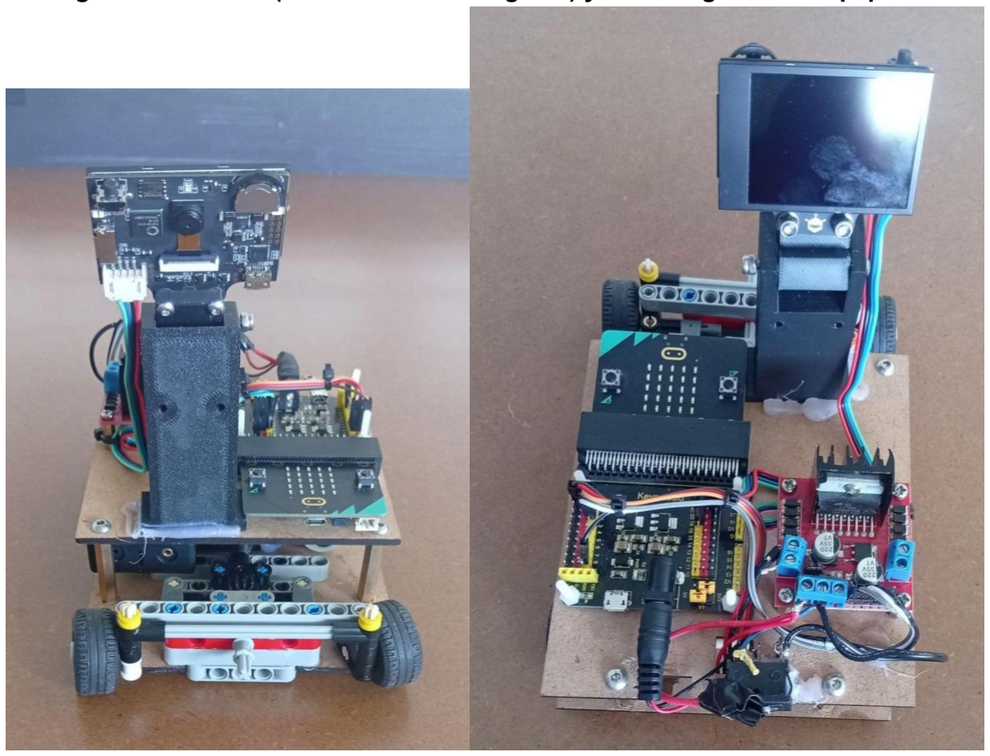
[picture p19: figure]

- Fotografías del robot (desde todos los ángulos) y una fotografía del equipo.

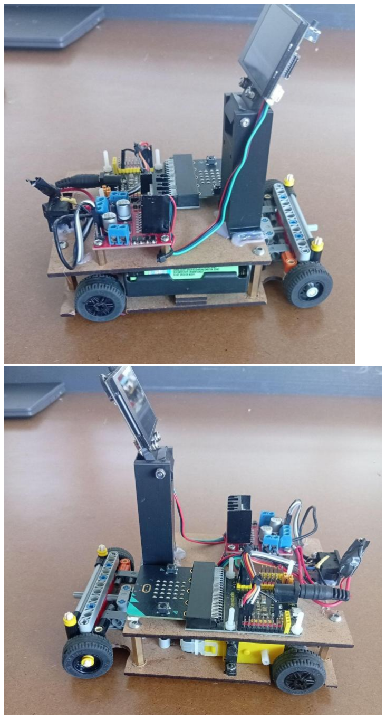
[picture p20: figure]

- Vídeo demostrativo mostrando el robot funcionando de manera autónoma en las diferentes regiones
- Repositorio público en GitHub
- El código empleado
- Documentación del proyecto
- (Opcional) Modelos 3D o archivos para la fabricación de piezas si las hubiera
- Un archivo README.md con una descripción clara de la solución, los módulos del código y su relación con los componentes del robot, que recoja: el proceso de desarrollo, las decisiones técnicas adoptadas y los resultados obtenidos.
- Código comentado y documentado para facilitar su comprensión por parte del jurado

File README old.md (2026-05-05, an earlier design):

# WRO Robotics Symposium, May 2026 – Ciudad Real
**Colegio Nuestra Señora de las Mercedes – Herencia**

---

## Technical Description

### Development
The robot's development began with a small wooden board used for prototyping. We then designed the chassis using vector drawing software to manufacture it with a laser cutter. 

The structure consists of two distinct levels:
* **Lower Level:** Houses the steering system, servo motor, and batteries.
* **Upper Level:** Contains the electronic components.

### Challenges
After resolving a chassis issue, we designed the upper deck to hold the Micro:bit, its expansion board, the power switch, and the L298N driver. We also integrated a mount to secure the 180º servo on the lower section. 

During assembly, we installed the battery pack and the geared DC motor. We added pillars to join both levels and wired all components. A hardware setback occurred when the switch broke; it was replaced with the current, more durable one. Lastly, we 3D printed a custom mount to elevate the HuskyLens AI camera above other components and connected it to the expansion board. Once the hardware was finalized, we began programming and testing on custom-made obstacle courses to debug the code.

---

## Hardware Components

| Category | Components |
| :--- | :--- |
| **Microcontroller** | Micro:bit board, Keyestudio Shield |
| **Motors & Drivers** | DC motor with gearbox, L298N motor driver, 180º Servo motor |
| **Sensors / Vision** | HuskyLens V1 AI Camera |
| **Power Supply** | 18650 LiPo battery holder (2 in series), Power switch |
| **Mechanics** | Lego wheels, Rack and pinion + linkage system (Lego parts) |
| **Custom Elements** | 3D printed parts (gears, mounts, and couplings) |

---

## Technical Decisions & Results

We successfully built a functional basic robot. Although its movement did not meet our initial expectations, we believe that with more time and dedication, it could have performed at a high level.

### Design Choices
* **AI Camera Implementation:** Elevated by several centimeters to improve the field of view and maintain horizon control.
* **Core Hardware:** Relied on Micro:bit and dedicated expansion shields for accessible and robust processing.
* **Form Factor:** Maintained a compact robot design to easily navigate tight courses.

### Mobility & Power
* **Steering:** Managed by a 180º Servo (operational angles: ±45º).
* **Traction:** Geared DC motor providing rear-wheel drive.
* **Power Management:** L298N driver dedicated to DC motor power distribution.

---

## Operation & Logic

The objective is for the robot to autonomously avoid obstacles based on specific environmental instructions. The system was programmed with two main goals:
1.  **Obstacle Avoidance:** Represented by object colors (IDs) 1, 2, and 3.
2.  **Parking (Goal):** Represented by color (ID) 4 *(Note: Goal not fully achieved during final testing)*.

### Startup and Mechanics
* **Steering Logic:** The robot utilizes a "rack and pinion" steering system controlled by a servo motor on pin `P0`. A 90° angle represents the neutral position (straight wheels), while 55° and 135° trigger lateral turns.
* **Traction Logic:** Forward and backward movement is managed via three pins (`P1`, `P2`, `P8`). `P2` and `P8` act as logic switches (0 or 1) to determine direction. `P1` sends a PWM (analog) signal to regulate speed, ranging from 0 (stopped) to 1023 (max speed).
* **Camera Logic:** The HuskyLens is initialized via I2C communication and configured exclusively in "Color Recognition" mode.

### Behavioral Scenarios
* **Parking Mode (ID 4):** Once detected, parking takes absolute priority. The robot accelerates to maximum speed (1023) and dynamically adjusts steering to keep the target centered. If the object's Y-coordinate exceeds 200 (meaning it is directly in front/below), the robot assumes it has reached the goal, stops, and displays an "X" on the LED matrix.
* **Wall Detection (ID 3):** The robot immediately brakes, steers away from the wall's center, reverses, and executes an "S" maneuver to safely bypass it.
* **Small Obstacles (IDs 1 & 2):** The robot turns its wheels, reverses slightly to create space, and straightens up. Turn directions are dictated by whether the detected color is Red (1) or Green (2).
* **Default State:** When no objects are detected, the steering remains straight (90°) and the robot moves at a moderate speed of 750, constantly scanning for new inputs.

---

## Code Documentation (Excerpts)

```typescript
/**
 * Continuous forward motion function.
 * Sets traction pins and applies speed.
 */
function moveForward(speed: number) {
    // P2 to 0 and P8 to 1 set the motor direction (Forward)
    pins.digitalWritePin(DigitalPin.P2, 0)
    pins.digitalWritePin(DigitalPin.P8, 1)
    // P1 regulates speed via analog signal (0 to 1023)
    pins.analogWritePin(AnalogPin.P1, speed)
}

// MAIN LOOP
input.onButtonPressed(Button.A, function () {
    while (true) {
        // 1. Exit condition: Stop if the race is finished.
        if (raceFinished) {
            stop(0)
            return
        }

        // 2. HuskyLens Data Request
        huskylens.request()
        Color = huskylens.readBox_s(Content3.ID)

        // If ID 4 (Finish Line) is detected, activate Finish Mode
        if (Color == 4) {
            finishMode = true
        }

        // ==========================================
        // FINISH LINE LOGIC (Targeting Color 4)
        // ==========================================
        if (finishMode) {
            basic.showIcon(IconNames.Target)
            if (Color == 4) {
                posX = huskylens.readeBox(Color, Content1.xCenter)
                posY = huskylens.readeBox(Color, Content1.yCenter)

                // Steering Logic: Keep the object centered
                if (posX < 140) {
                    servos.P0.setAngle(55) // Correct left
                } else if (posX > 180) {
                    servos.P0.setAngle(135) // Correct right
                } else {
                    servos.P0.setAngle(90) // Straight
                }

                moveForward(1023) // Max speed towards finish

                // If posY > 200, the object is at the bottom (directly in front)
                if (posY > 200) {
                    raceFinished = true
                    stop(0)
                    basic.showIcon(IconNames.No)
                }
            } else {
                // If finish line is lost, try going straight for 0.5s
                servos.P0.setAngle(90)
                moveForward(1023)
                basic.pause(500)
                raceFinished = true
                stop(0)
                basic.showIcon(IconNames.No)
            }
            return
        }

        // ==========================================
        // OBSTACLE AVOIDANCE LOGIC (IDs 1, 2, and 3)
        // ==========================================
        if (Color > 0 && Color <= 3) {
            posX = huskylens.readeBox(Color, Content1.xCenter)
            posY = huskylens.readeBox(Color, Content1.yCenter)
            width = huskylens.readeBox(Color, Content1.width)
            height = huskylens.readeBox(Color, Content1.height)

            // --- COLLISION DETECTION ---
            // Reverse if: object is low (near), too wide (wall), or too tall.
            if (posY > 140 || width > 100 || height > 100) {
                if (Color == 3) {
                    // WALL LOGIC (Color 3): Reverse while steering away
                    if (posX >= 160) {
                        servos.P0.setAngle(135)
                    } else {
                        servos.P0.setAngle(55)
                    }
                    stop(150)
                    reverse(1023, 1000)
                    stop(150)
                    
                    // Exit maneuver (S-curve)
                    if (posX >= 160) {
                        servos.P0.setAngle(55)
                    } else {
                        servos.P0.setAngle(135)
                    }
                    moveForwardTimed(750, 600)
                    
                    if (posX >= 160) {
                        servos.P0.setAngle(135)
                    } else {
                        servos.P0.setAngle(55)
                    }
                    moveForwardTimed(750, 400)
                } else {
                    // SMALL OBSTACLES (IDs 1 & 2): Quick reverse tap
                    if (Color == 1) {
                        servos.P0.setAngle(55)
                    } else {
                        servos.P0.setAngle(135)
                    }
                    stop(150)
                    reverse(1023, 400)
                }
                servos.P0.setAngle(90) // Straighten wheels
            }
        }
    }
})
```

---

## Demonstration

Watch the robot operating autonomously across different sections here:  
[**Autonomous Operation Video (YouTube Shorts)**](https://youtube.com/shorts/AhCgXqGC2gI?feature=share)

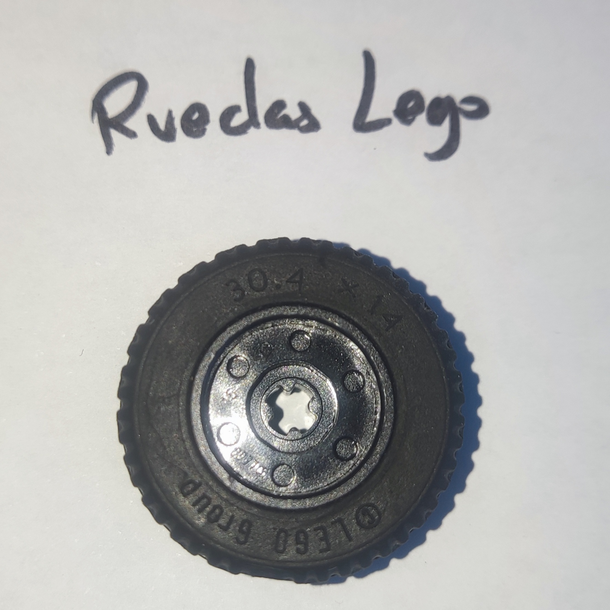
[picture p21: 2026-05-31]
images/Ruedas lego.jpeg

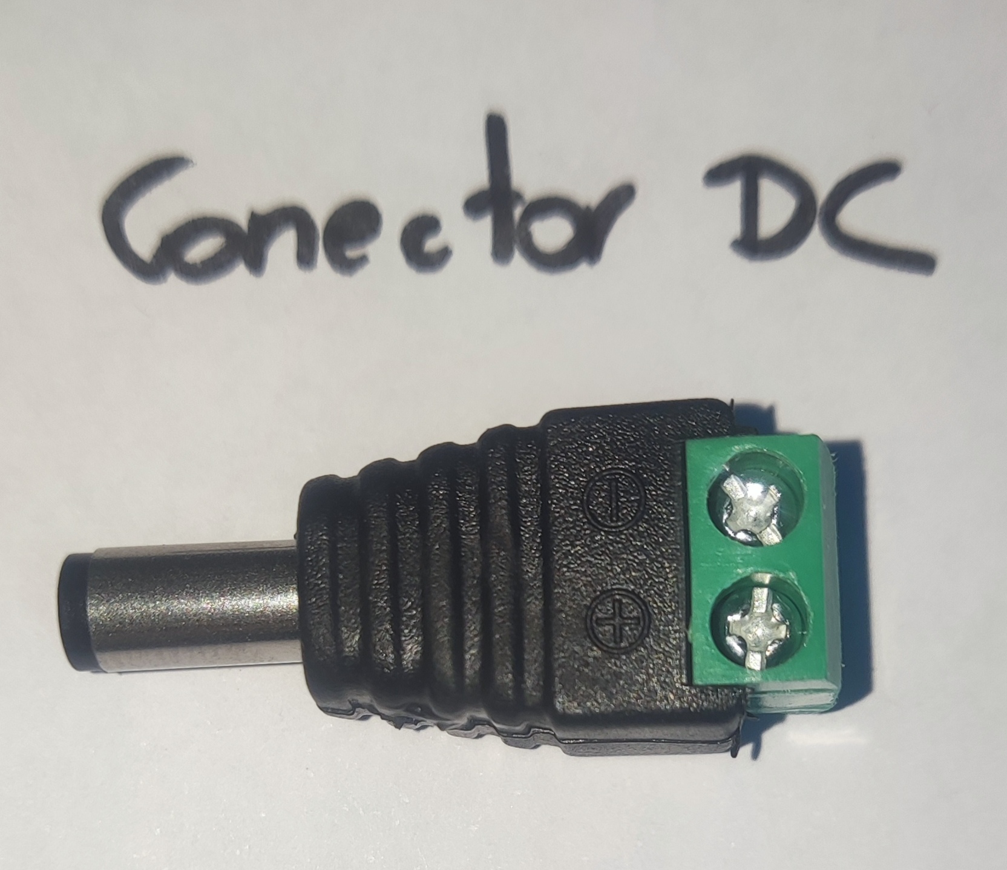
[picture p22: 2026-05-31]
images/Conector DC.jpeg

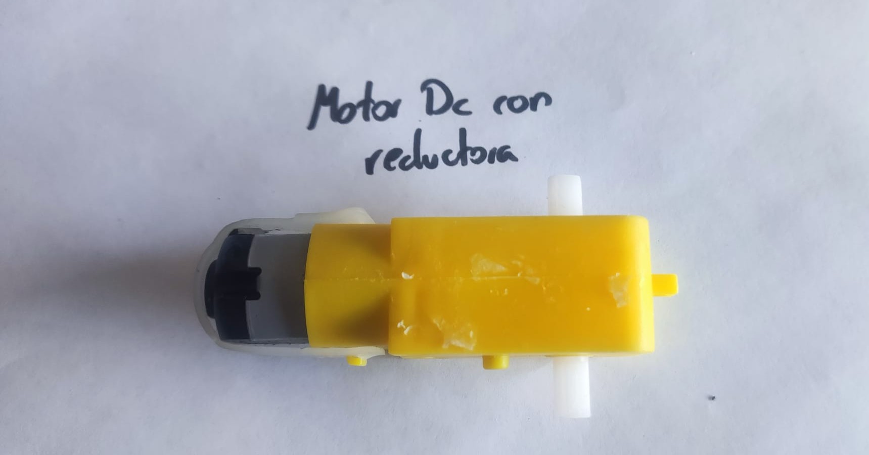
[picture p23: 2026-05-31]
images/Motor con reductora.jpeg

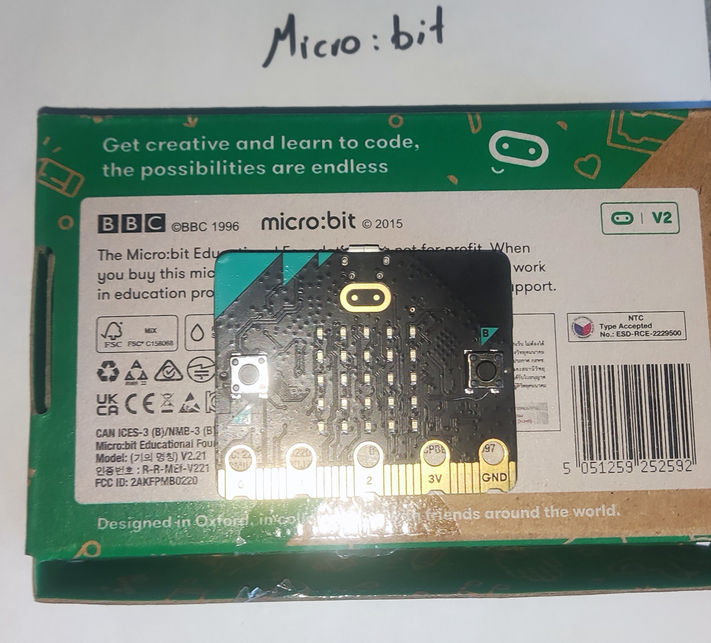
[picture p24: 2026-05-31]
images/Micro bit.jpeg

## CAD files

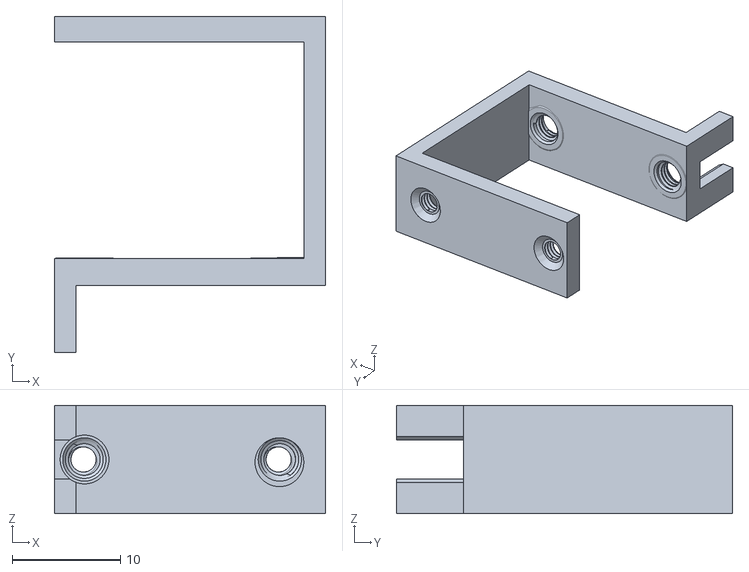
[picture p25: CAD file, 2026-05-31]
parts/encaje motor dc.stl
25.0 x 31.0 x 10.0

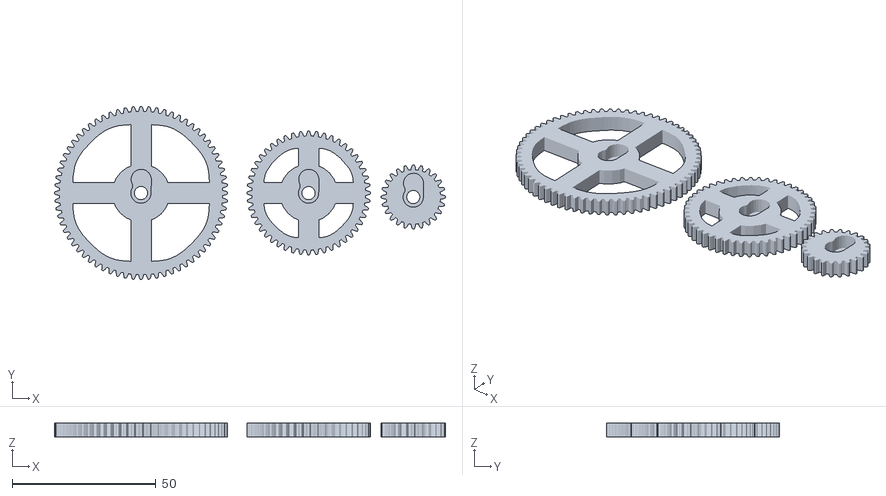
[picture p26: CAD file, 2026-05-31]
parts/Engranajes.stl
136.2 x 60.4 x 5.00

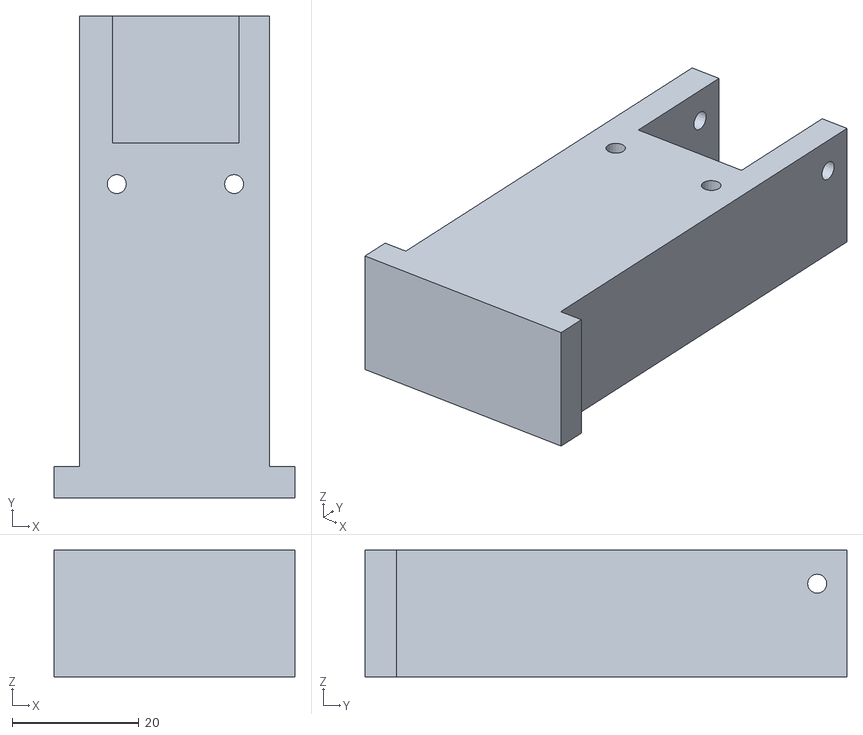
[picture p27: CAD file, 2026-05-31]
parts/soporte huskylens modificado (2).stl
38.0 x 76.0 x 20.0

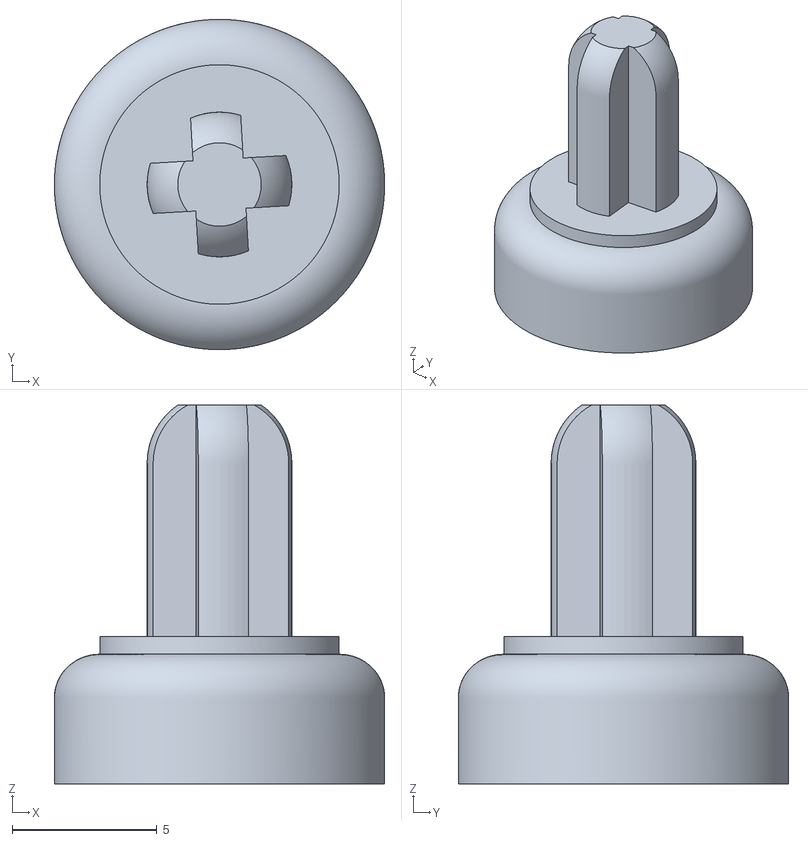
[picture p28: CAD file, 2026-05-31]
parts/acople lego servo.stl
11.4 x 11.4 x 13.1

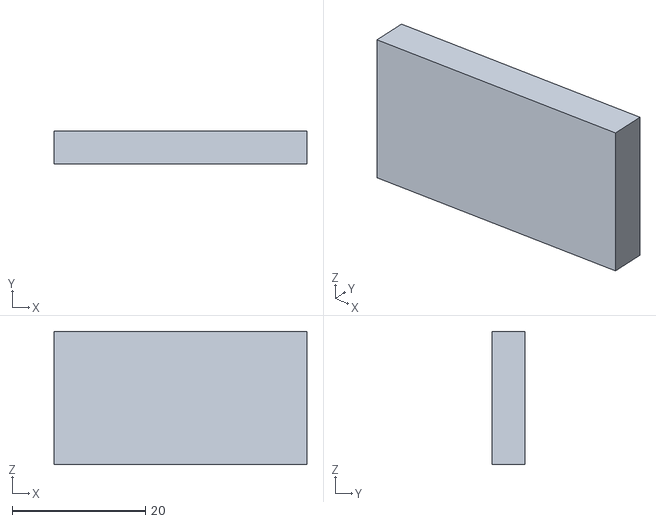
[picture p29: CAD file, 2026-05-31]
parts/soporte huskylens modificado (1).stl
38.0 x 5.00 x 20.0

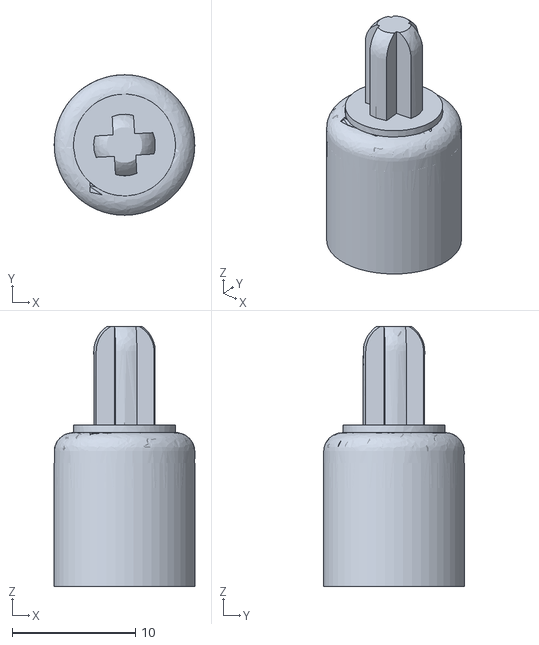
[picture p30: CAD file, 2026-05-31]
parts/Acople lego 5mm.stl
11.4 x 11.4 x 21.1
